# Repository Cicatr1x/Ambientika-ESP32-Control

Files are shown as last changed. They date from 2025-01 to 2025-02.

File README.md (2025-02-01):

# Ambientika-ESP32-Control

A simple control system for Ambientika ventilation systems that uses the 24V onboard voltage and an ESP32 to control the fan's direction and speed, as well as a simple automatic mode.

## Components

- **ESP32 D1 Mini**: The microcontroller used to control the fan.
- **MP1584EN DC-DC 3A Step-Down Converter**: The largest block in the schematic, used to step down the 24V to 5V for the ESP32.
- **IRLZ44N N-Channel Mosfet**: Used to control the fan's direction and speed.
- **3 x 10kOhm Resistors**: Used in the voltage divider and as a pull-down resistor.
- **Schottky Diode 1N5819**: Prevents damage to the circuit from inductive back currents during direction changes.
- **24V and GND**: Taken from the 3-pin connector of the Ambientika.

## Circuit Description

- **Voltage Regulation**: The 24V from the Ambientika is stepped down to 5V using the MP1584EN DC-DC Step-Down Converter to provide a suitable supply voltage for the ESP32 D1 Mini.
- **Voltage Divider**: Resistors R1 and R9 form a voltage divider that reduces the 24V to 12V. This voltage range (0-12V) is suitable for controlling the signal pin of the Ambientika.
- **Protection**: The Schottky Diode (1N5819) prevents damage to the circuit from inductive back currents during direction changes.
- **Pull-Down Resistor**: Resistor R10 is connected between the gate and source of the MOSFET as a pull-down resistor to ensure a clear signal at the drain.
- **Fan Connection**: The fan is connected directly to 24V and GND, with the signal voltage taken from the junction of the voltage divider.

## Schematic

A basic schematic for this project can be found in the `schematic` folder: [Vent_control_Ambientika.pdf](./schematic/Vent_control_Ambientika.pdf).

Thanks to [@comtel2000](https://github.com/comtel2000) here is a nice and easy to comprehend fritzing schematic.

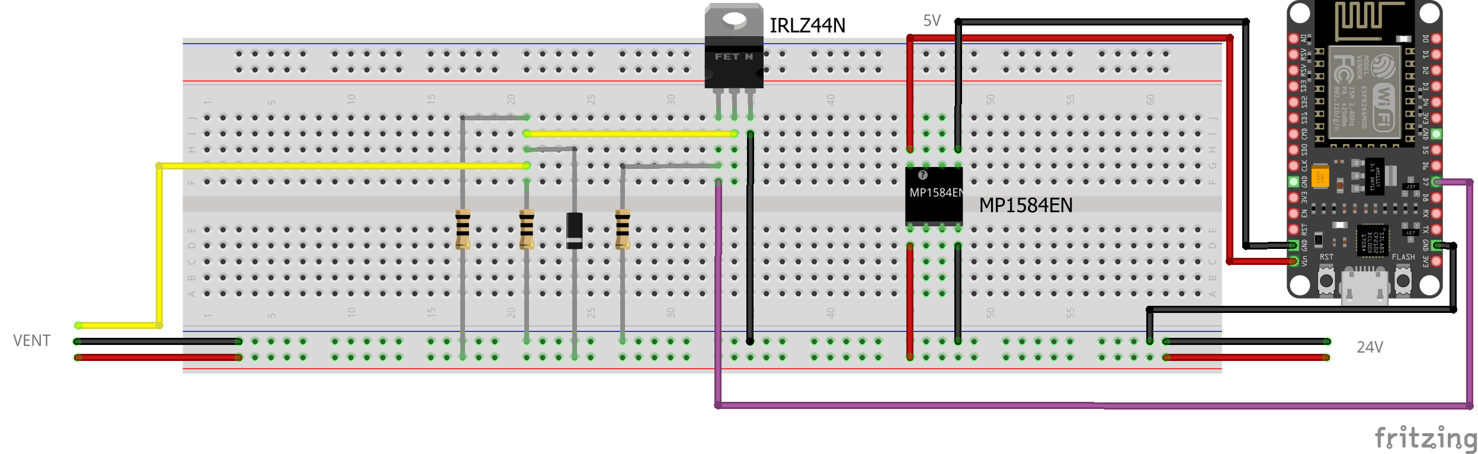
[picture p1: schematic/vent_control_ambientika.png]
fritzing schematic


## Configuration

The `config` folder contains an example ESPHome configuration file named [`example-config.yaml`](./config/example-config.yaml).

## Usage

1. Connect the components as described in the circuit description.
2. Upload the ESPHome configuration (`example-config.yaml`) to the ESP32.
3. Power the system using the 24V supply from the Ambientika.
4. Control the fan's direction and speed using the ESP32.

## Automatic Mode

The ESP32 can be configured to automatically control the fan based on sensor inputs or predefined conditions.

---

This project provides a simple and effective way to control Ambientika ventilation systems using an ESP32, making it easy to integrate with home automation systems.

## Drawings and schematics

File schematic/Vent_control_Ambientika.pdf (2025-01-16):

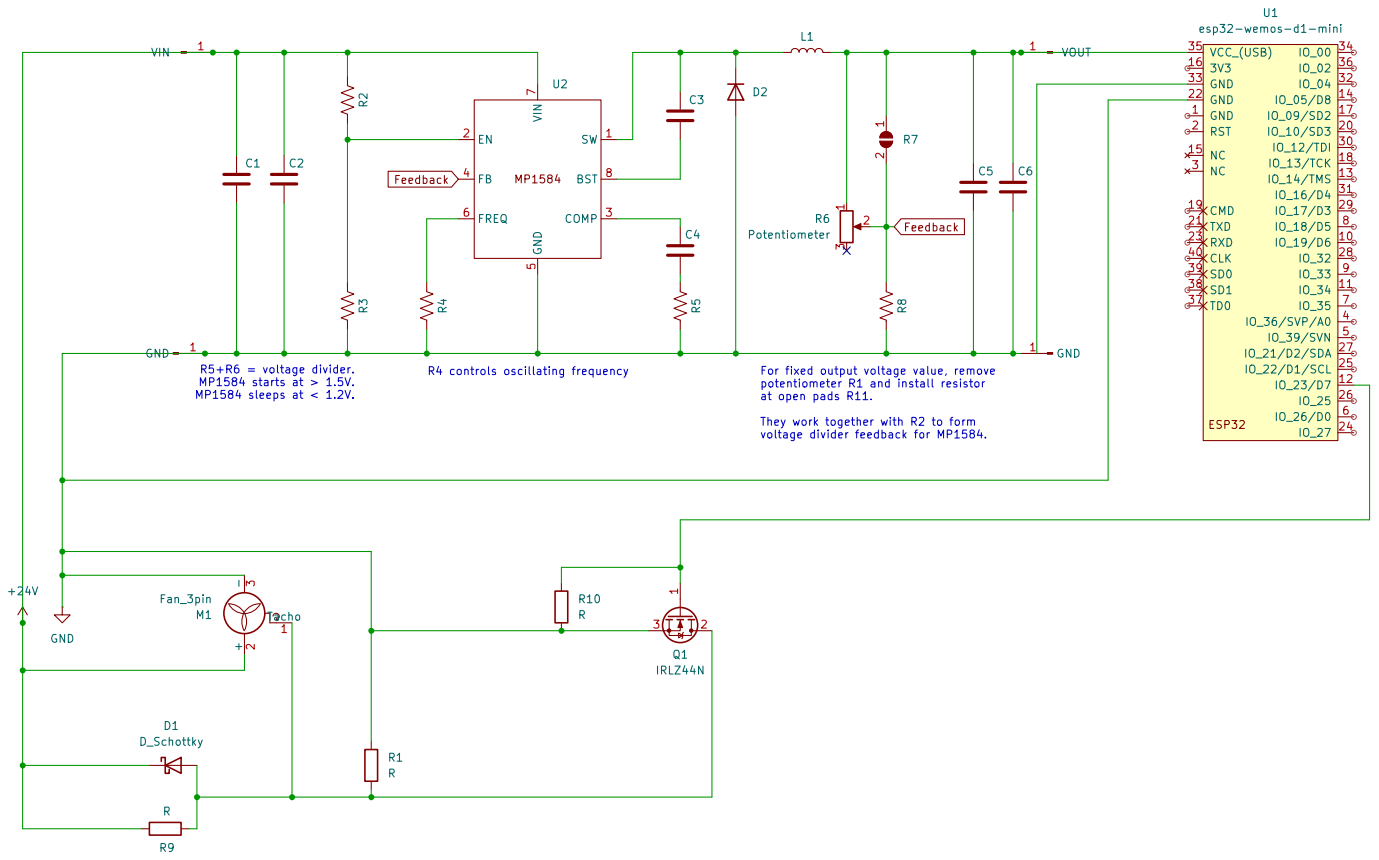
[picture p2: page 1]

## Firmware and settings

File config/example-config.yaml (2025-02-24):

esphome:
  name: vent-controller-LOCATION
  friendly_name: vent-LOCATION
  on_boot:
    priority: -10  # Low priority to let other components initialize first
    then:
      - delay: 2s  # Wait for 2 seconds before setting fan state
      - lambda: |-
          // Set fan to an initial PWM level (e.g., 70% PWM)
          id(current_pwm_level) = 70.0;  // Adjust the percentage as needed
          id(fanhub_pwm).set_level(id(current_pwm_level) / 100.0);
          id(fan_pwm_level).publish_state(id(current_pwm_level));  // Update fan PWM sensor

esp32:
  variant: esp32
  board: esp32dev
  framework:
    type: arduino

# Enable logging
logger:
#  level: INFO
  
# Enable Home Assistant API
api:
  encryption:
    key: !secret api_encryption_key

ota:
  platform: esphome
  password: !secret ota_password

wifi:
  ssid: !secret wifi_ssid
  password: !secret wifi_password

  domain: CHANGE_ME

  manual_ip:
    static_ip: CHANGE_ME
    gateway: CHANGE_ME
    subnet: CHANGE_ME  
    dns1: CHANGE_ME
    dns2: CHANGE_ME

  power_save_mode: none

  # Enable fallback hotspot (captive portal) in case wifi connection fails
  ap:
    ssid: "Vent Controller Fallback Hotspot"
    password: "CHANGE_ME"

web_server:
  version: 3

captive_portal:

##########################################################################################################################

preferences:
  flash_write_interval: 3min # Prevents flash writes every 1min in automatic mode

globals:
  - id: current_pwm_level
    type: float
    restore_value: yes  # Ensures the previous PWM level is restored after restart
    initial_value: '70.0'  # Starts at 0 to avoid full power on reboot

  - id: transition_target
    type: float
    restore_value: no
    initial_value: '0.0'

  - id: final_target_speed
    type: float
    restore_value: no
    initial_value: '0.0'

  - id: step_size
    type: float
    restore_value: no
    initial_value: '2.0'  # PWM step size in percent

  - id: interval_duration
    type: float
    restore_value: no
    initial_value: '0.5'  # Interval duration in seconds
    
button:
  - platform: restart
    name: "ESP Restart"

output:
  - platform: ledc
    pin: GPIO23
    frequency: 20000 Hz
    id: fanhub_pwm
    inverted: true

fan:
  - platform: speed
    output: fanhub_pwm
    name: "PWM Fan"
    restore_mode: ALWAYS_OFF  # Ensures fan stays off after restart

# Selects for various modes
select:
  - platform: template
    name: "Fan Speed"
    id: speed_select
    options:
      - "Sleep"
      - "Slow"
      - "Medium"
      - "Fast"
      - "Boost"
    optimistic: true
    on_value:
      then:
        - lambda: |-
            std::string fan_speed = id(speed_select).state.c_str();
            bool laufrichtung = id(fan_direction).state;

            // Define speed targets based on fan direction (Laufrichtung)
            std::map<std::string, std::array<int, 2>> speeds = {
              {"Sleep", {59, 81}},
              {"Slow", {56, 83}},
              {"Medium", {52, 86}},
              {"Fast", {42, 96}},
              {"Boost", {29, 100}}
            };

            if (speeds.find(fan_speed) != speeds.end()) {
              // Select PWM based on Laufrichtung (direction)
              int target_pwm_percentage = laufrichtung ? speeds[fan_speed][0] : speeds[fan_speed][1];
              id(final_target_speed) = target_pwm_percentage;
              id(transition_target) = target_pwm_percentage;  // Trigger immediate transition
              
              ESP_LOGD("fan_control", "Changing fan speed to %s. Transitioning to final target PWM: %d", fan_speed.c_str(), target_pwm_percentage);
            } else {
              ESP_LOGE("fan_control", "Unknown fan speed: %s", fan_speed.c_str());
            }

# Monitoring sensors
sensor:
  - platform: wifi_signal
    name: "Fan Controller WiFi Signal"
    update_interval: 60s

  - platform: uptime
    name: "Fan Controller Uptime"

  - platform: template
    name: "Fan PWM Level"
    id: fan_pwm_level
    lambda: |-
      return id(current_pwm_level);
    unit_of_measurement: "%"
    accuracy_decimals: 0
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

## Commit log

2025-01-16 Add folder for schematics
2025-01-16 Add files via upload
    Basic schematic
2025-02-01 add fritzing draft
    [vent_control_ambientika.fzz]
2025-02-01 add 24V IN
    [vent_control_ambientika.fzz]
2025-02-02 prevent flash writes every 1min in automatic mode (current_pwm_level)
    current_pwm_level toggles every 90sec and the default flash write
    interval is 1min.
    [example-config.yaml]
